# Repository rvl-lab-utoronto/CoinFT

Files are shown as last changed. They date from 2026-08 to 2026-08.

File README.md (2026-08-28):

<h1>CoinFT</h1>

#### Reproduced from [CoinFT](https://coin-ft.github.io)

Fabrication and calibration process for the CoinFTs, RVL edition. 

Please refer to their [official website](https://coin-ft.github.io) for the complete guide, this README is only intended for changes on the sensor for RVL's particular setup. 

## Catalog
- [Facility](#facility)
- [Components](#components)
- [Equipment](#equipment)
- [Fabrication](#fabrication)
- [Calibration](#calibration)
- [Sensors](#sensors)

## Facility
You'll need access to [CRAFT](https://craftmicrofluidics.ca/status-access/), it's one of the facilities at UofT that offers rental services for a degas chamber and a spin coater. You'll need to register a new account using RVL's payment method which you can get from Phebe. You'll also need to complete the general safety trainings. After that, you'll need to submit a request for an orientation at the <i>device foundry</i>. Finally, you'll need to book a training for the spin coater. In this case, the degas chamber isn't listed on their website as a separate device, so you'll be able to use it without any additional training. 

## Components
1. [PCB files](https://github.com/coin-ft/coin-ft/tree/main/hardware_files) can be found here
   - Feel free to order more stencils but we already have 2
2. [PCB ordering instruction](https://docs.google.com/document/d/e/2PACX-1vSQ-6q2MDwoBn2g9_u95RpvHrBDzH095R--uHuNxioFIZdZOnJKnvnTMS7yw188D1-z9awBrU9pWYNI/pub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)
3. There're some additional components needed to interface with the sensor:
   
| Item | Description | Qty | Unit Cost | Link |
|---|---|-----|---|---|
| 22 AWG wires | Signal wires | 1 | $20.50 | [link](https://www.amazon.ca/Fermerry-Stranded-Electric-Tinned-Copper/dp/B089CQHRDT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) |
| 1.25mm 4-pin JST connectors | Only use the female connectors | 1 | $11 | [link](https://www.amazon.ca/dp/B0F32G9B13?ref=ppx_yo2ov_dt_b_fed_asin_title&th=1) |
| 1.25mm 4-pin JST headers | Solder them onto the PCBs | 20 | $19.6 | [link](https://www.digikey.ca/en/products/detail/molex/0532610471/699096) 

We have a PSoC board and a Teensy 4.0 board in the lab, so you don't need to order additional ones.

4. 1200 Primer is intended to clean the surfaces of the PCB before applying the mold, the point of it is to improve adhesion. We were unable to find any 1200 Primer, so instead we used [99% IPA](https://www.amazon.ca/DELON-Isopropyl-Alcohol-percent-Rubbing/dp/B0DD4FSVT3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). It helps ensure that the surfaces are free of dust and can somewhat improve adhesion. In this case, you don't need to use a fume hood when cleaning the surface with IPA.
5. The original silicone rubber layer was made using two types of materials: TAP Silicone RTV Mold-Making System and Smooth-On Mold Max 40. However, we were unable to find TAP Silicone, so we only have Mold Max 40. This is fine, the instructions said that either material can be used.
6. The following picture shows some more components that we'll need, which we already have in the lab:
 Screenshot 2026-08-27 at 10 46 31 AM
7. We are replacing the acrylic parts with 3D printed parts including the holder for the PCBs, the guide rings for the weights and the calibration base. The CAD files can be found in the `CAD` folder.

## Equipment
1. A soldering iron
2. A 3D printer

## Fabrication 
The [official hardware instructions](https://docs.google.com/presentation/d/1NiOAXyq2A7fU8aHAD35k3iYaZIU_IhwRRHh8g923IFc/edit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) 
- Top:
   1. Sand and clean the PCBs (with IPA 99%) at Myhal
   2. Carry the PCBs in a Petri dish to CRAFT (at Bahen). Mix and degas the chemical mixtures (Mold Max 40 part A & B), then apply the mold.
   3. Leave the PCBs to cure at Myhal for 24 hours
- Bottom:
   1. Sand and clean the PCBs
   2. Bring the cured top PCB and the sanded bottom PCB to CRAFT.
   3. Mix and degas the chemical mixtures (1400 RPM for 2 minutes), then spin coat the bottom PCB at 3100 RPM for 1 minute and 20 seconds (you will have to experiment with the exact time)
   4. Place the top PCB on top of the bottom PCB and leave it to cure for 24 hours (or longer)
- Soldering:
  1. Solder the yellow shielding to GND (G) not SHD, do not follow their tutorial.
- Sanding: 
  <i>Do not sand too much!</i> 
The following picture shows the amount of sanding you should aim for. You can sand a little more, but try to get a more even exposure.



## Calibration
CoinFT doesn't directly return FT values, instead it measures capacitance which we need to map to the corresponding FT values. So, we'll use the Bota SensOne FT sensors as the reference/ground truth to calibrate the CoinFT.

Bota sensors show fewer oscillations at lower frequencies, and for a sensitive device like CoinFT, it is preferable to operate the Bota sensors at a frequency of around 400Hz or less.
 
When collecting data to train the model, start with slower presses to get a sense of the sensors’ sensitivities and to ensure that the CoinFTs and Bota are properly synced.

For reference, ~15 training sets (30s each) of stationary objects + slow presses should give you results like this, with mean-squared error per axis (Newtons): Fx: 0.000512, Fy: 0.000391, and Fz: 0.053102
CFT24_MLP_test_force_results

The PSoC board (the red one) should be used to flash and calibrate the CoinFT sensor. Once the board has been calibrated, remove all the soldered wires from the sensor and reconnect the signal connections to the Teensy board. [Link to the Teensy code](https://github.com/coin-ft/coin-ft/tree/main/hardware_files/Teensy)

## Sensors
As of September 2026, there are three fabricated CoinFT sensors in the lab labeled A, B and C.

I have uploaded the firmware for sensor A, B and C (they are ready to use) and trained individual models for sensors A and B, located in the `trained_model` folder.

The sensors may need to be recalibrated given that the rubber ages and becomes less elastic. If recalibration is needed, follow the instructions in README.md inside the `src` folder to collect and re-train the models.

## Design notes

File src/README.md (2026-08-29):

## Setup
Ensure the correct orientation


## Notes
1. Run sudo for every file
2. The Bota sensor is collecting data at 400Hz.
3. Both sensors stop collecting at the same time, the collected dataset is then trimmed by `trim_duration` from the end of the episode, ensuring that the timestamps are synced. <i>The sensors are NOT hardware synced</i>. 
4. The total collection time is `trim_duration` + 5s
5. You will need to intentionally twist the top PCB around the Z-axis to collect sufficient data for training the Z-axis torque (ie Mz), otherwise the trained model may not be accurate. 

## Run
`sudo python3 coinft_tune.py --data_type train --bota_rate 400 --trim_duration 30`
- data_type: train, test or val 
- bota_rate: default 400Hz
- trim_duration: length of each episode, default 30s

Run this after all data has been collected:
`sudo python3 data_processor.py`

Train the model:
`sudo python3 coinft_MLP_train.py`

Run CoinFT live:
`sudo python3 live_eval.py --model_dir sensor_A --recording_time 30`
for models located in the `/trained_model/sensor_A` folder

## Models
1. `/trained_model/sensor_A` is trained on 18 episodes, 30s per episode, with Bota's frequency set to 400Hz.

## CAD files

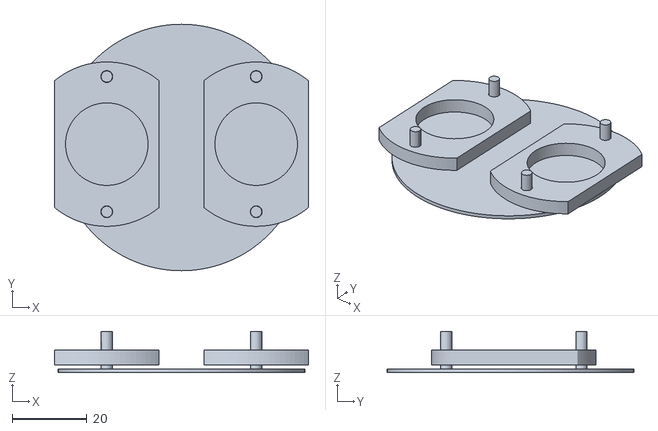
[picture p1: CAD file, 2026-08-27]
CAD/CoinFT_base.stl
68.0 x 66.0 x 11.0

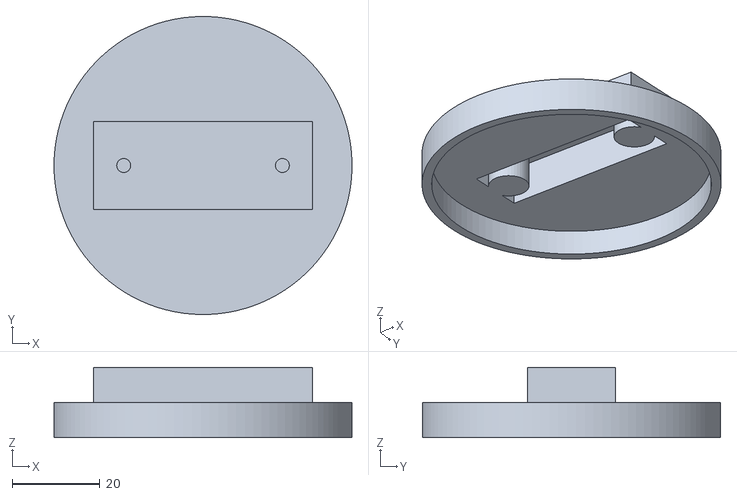
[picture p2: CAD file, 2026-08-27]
CAD/CoinFT_Testbed.stl
68.0 x 68.0 x 16.0

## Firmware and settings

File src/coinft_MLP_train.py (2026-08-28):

import torch
import torch.nn as nn
import torch.optim as optim
from torch.utils.data import Dataset, DataLoader
import numpy as np
import h5py
import json
import matplotlib.pyplot as plt
import os

# --- CONFIGURATION ---
BATCH_SIZE = 32
LEARNING_RATE = 1e-3
EPOCHS = 30
L2_REG = 1e-4  # L2 Regularization
SEED = 42
SENSOR_NAME = "CFT24"
MODEL_NAME = f"{SENSOR_NAME}_MLP"

SCRIPT_DIR = os.path.dirname(os.path.abspath(__file__))
DATA_DIR = os.path.join(SCRIPT_DIR, '..', 'data')
CONFIG_DIR = os.path.join(SCRIPT_DIR, '..', 'hardware_configs')

# Force CPU (no CUDA)
device = torch.device("cpu")
print(f"Using device: {device}")

# Set random seed for reproducibility
torch.manual_seed(SEED)
np.random.seed(SEED)

# --- 1. DATASET CLASS ---
class CoinFTDataset(Dataset):
    def __init__(self, h5_path):
        # Load data into memory
        with h5py.File(h5_path, 'r') as f:
            self.X = torch.tensor(f['data'][:], dtype=torch.float32)
            self.Y = torch.tensor(f['label'][:], dtype=torch.float32)

    def __len__(self):
        return len(self.X)

    def __getitem__(self, idx):
        return self.X[idx], self.Y[idx]

# --- 2. NETWORK ARCHITECTURE ---
class CoinFTNet(nn.Module):
    def __init__(self, input_dim, output_dim):
        super(CoinFTNet, self).__init__()
        self.net = nn.Sequential(

            # Layer 1: 128
            nn.Linear(input_dim, 128),
            nn.ReLU(),

            # Layer 2: 64
            nn.Linear(128, 64),
            nn.ReLU(),

            # Layer 3: 36
            nn.Linear(64, 36),
            nn.ReLU(),

            # Layer 4: 24
            nn.Linear(36, 24),
            nn.ReLU(),

            # Layer 5: 12
            nn.Linear(24, 12),
            nn.ReLU(),

            # Output Layer: 6 (Regression)
            nn.Linear(12, output_dim)
        )

    def forward(self, x):
        return self.net(x)

def train_pipeline():
    # --- 3. DATA LOADING ---
    print("Loading datasets...")
    train_dataset = CoinFTDataset(os.path.join(DATA_DIR, 'train.h5'))
    val_dataset   = CoinFTDataset(os.path.join(DATA_DIR, 'val.h5'))
    test_dataset  = CoinFTDataset(os.path.join(DATA_DIR, 'test.h5'))

    train_loader = DataLoader(train_dataset, batch_size=BATCH_SIZE, shuffle=True)
    val_loader   = DataLoader(val_dataset, batch_size=BATCH_SIZE, shuffle=False)
    # Test loader: batch_size = total size to predict all at once later
    test_loader  = DataLoader(test_dataset, batch_size=len(test_dataset), shuffle=False)

    # Determine dimensions dynamically
    input_dim = train_dataset.X.shape[1]  # Should be 12 based on CoinFT raw data
    output_dim = train_dataset.Y.shape[1] # Should be 6 (Fx...Mz)
    print(f"Input Dim: {input_dim}, Output Dim: {output_dim}")

    # --- 4. MODEL SETUP ---
    model = CoinFTNet(input_dim, output_dim).to(device)

    # Loss function (RegressionLayer)
    criterion = nn.MSELoss()

    # Optimizer (Adam with L2 Regularization)
    optimizer = optim.Adam(model.parameters(), lr=LEARNING_RATE, weight_decay=L2_REG)

    # --- 5. TRAINING LOOP ---
    print("\nStarting training...")
    train_losses = []
    val_losses = []

    for epoch in range(EPOCHS):
        model.train()
        running_loss = 0.0

        for X_batch, Y_batch in train_loader:
            X_batch, Y_batch = X_batch.to(device), Y_batch.to(device)

            optimizer.zero_grad()           # Clear gradients
            outputs = model(X_batch)        # Forward pass
            loss = criterion(outputs, Y_batch) # Compute loss
            loss.backward()                 # Backward pass
            optimizer.step()                # Update weights

            running_loss += loss.item() * X_batch.size(0)

        epoch_train_loss = running_loss / len(train_dataset)
        train_losses.append(epoch_train_loss)

        # Validation Step
        model.eval()
        val_loss = 0.0
        with torch.no_grad():
            for X_val, Y_val in val_loader:
                X_val, Y_val = X_val.to(device), Y_val.to(device)
                preds = model(X_val)
                loss = criterion(preds, Y_val)
                val_loss += loss.item() * X_val.size(0)

        epoch_val_loss = val_loss / len(val_dataset)
        val_losses.append(epoch_val_loss)

        print(f"Epoch {epoch+1}/{EPOCHS} | Train Loss: {epoch_train_loss:.6f} | Val Loss: {epoch_val_loss:.6f}")

    print("Training complete.")

    # --- 6. SAVE MODEL (PyTorch & ONNX) ---
    pth_path = os.path.join(CONFIG_DIR, f"{MODEL_NAME}.pth")
    onnx_path = os.path.join(CONFIG_DIR, f"{MODEL_NAME}.onnx")

    # Save standard PyTorch model
    torch.save(model.state_dict(), pth_path)

    # Export to ONNX
    dummy_input = torch.randn(1, input_dim).to(device)
    torch.onnx.export(model, dummy_input, onnx_path,
                      input_names=['input'], output_names=['output'])

    print(f"Models saved to:\n  {pth_path}\n  {onnx_path}")

    # --- 7. EVALUATION & DENORMALIZATION ---
    print("\nEvaluating on Test Set...")

    # Load Normalization Constants
    with open(os.path.join(CONFIG_DIR, f'{SENSOR_NAME}_norm.json'), 'r') as f:
        norm = json.load(f)
        mu_y = np.array(norm['mu_y'])
        sd_y = np.array(norm['sd_y'])

    model.eval()
    with torch.no_grad():
        # Get all test data
        X_test, Y_test_norm = next(iter(test_loader))
        X_test = X_test.to(device)

        # Predict (Normalized Space)
        pred_norm = model(X_test).cpu().numpy()
        Y_test_norm = Y_test_norm.numpy()

        # Denormalize: pred = pred_n * std + mean
        pred_real = (pred_norm * sd_y) + mu_y
        Y_test_real = (Y_test_norm * sd_y) + mu_y

    # Calculate MSE per axis
    mse_per_dim = np.mean((pred_real - Y_test_real)**2, axis=0)

    labels = ['Fx', 'Fy', 'Fz', 'Mx', 'My', 'Mz']
    print("\nMean-squared error per axis (Newtons / Nm):")
    for i, label in enumerate(labels):
        print(f"  {label} : {mse_per_dim[i]:.6f}")

    # --- 8. VISUAL CHECK (Matplotlib) ---
    plot_len = len(Y_test_real)

    fig, axs = plt.subplots(3, 2, figsize=(10, 10))
    axs = axs.ravel()

    for i in range(6):
        axs[i].plot(Y_test_real[:plot_len, i], 'b-', label='True')
        axs[i].plot(pred_real[:plot_len, i], 'r--', label='Pred')
        axs[i].set_title(f'Axis {labels[i]}')
        if i == 0: axs[i].legend()

    plt.tight_layout()

    fig_path = os.path.join(DATA_DIR, f"{MODEL_NAME}_results.png")
    plt.savefig(fig_path)
    plt.show()

if __name__ == "__main__":
    train_pipeline()

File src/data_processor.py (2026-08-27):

import os
import glob
import numpy as np
import h5py
import json

# --- CONFIGURATION ---
SENSOR_NAME = 'CFT24'
SCRIPT_DIR = os.path.dirname(os.path.abspath(__file__))
# Path to raw data (relative to this script)
DATA_DIR = os.path.join(SCRIPT_DIR, '..', 'data')
# Path to save processed data
SAVE_DATA_DIR = os.path.join(SCRIPT_DIR, '..', 'data')
SAVE_JSON_DIR = os.path.join(SCRIPT_DIR, '..', 'hardware_configs')
JSON_FILENAME = f'{SENSOR_NAME}_norm.json'  # Name of your JSON constants file

def process_data():
    # 1. Setup Directories
    if not os.path.exists(SAVE_DATA_DIR):
        os.makedirs(SAVE_DATA_DIR)
        print(f"Created directory: {SAVE_DATA_DIR}")
    if not os.path.exists(SAVE_JSON_DIR):
        os.makedirs(SAVE_JSON_DIR)
        print(f"Created directory: {SAVE_JSON_DIR}")

    # 2. Find all HDF5 files matching the sensor name
    search_path = os.path.join(DATA_DIR, f"*{SENSOR_NAME}_calibrationData_*.h5")
    file_list = glob.glob(search_path)

    if not file_list:
        print(f"No files found in {search_path}")
        return

    print(f"Found {len(file_list)} files. Sorting by filename suffix...")

    # 3. Bucket files based on suffix (_train, _val, _test)
    data_buckets = {
        'train': {'sensor': [], 'ft': []},
        'val':   {'sensor': [], 'ft': []},
        'test':  {'sensor': [], 'ft': []}
    }

    for file_path in file_list:
        filename = os.path.basename(file_path)

        # Determine split type from filename
        if '_train.h5' in filename:
            split_type = 'train'
        elif '_val.h5' in filename:
            split_type = 'val'
        elif '_test.h5' in filename:
            split_type = 'test'
        else:
            print(f"Skipping file (unknown suffix): {filename}")
            continue

        # Load Data
        with h5py.File(file_path, 'r') as f:
            sensor_val = f['sensor_cal_data'][:]
            ft_val = f['bota_cal_FT'][:]  # was 'ati_cal_FT' -- now using Bota driver's key

            data_buckets[split_type]['sensor'].append(sensor_val)
            data_buckets[split_type]['ft'].append(ft_val)
            print(f"Loaded {split_type}: {filename}")

    # 4. Stack Arrays for each split
    # Helper to stack or return empty if no data found
    def stack_data(key):
        if not data_buckets[key]['sensor']:
            print(f"Warning: No data found for split '{key}'")
            return None, None
        return (np.vstack(data_buckets[key]['sensor']),
                np.vstack(data_buckets[key]['ft']))

    X_train, Y_train = stack_data('train')
    X_val, Y_val     = stack_data('val')
    X_test, Y_test   = stack_data('test')

    if X_train is None:
        print("Error: No training data found. Cannot compute normalization.")
        return

    print(f"\nData Split Dimensions:")

    if X_train is not None:
        print(f"Train | X: {X_train.shape}  Y: {Y_train.shape}")
    else:
        print("Train | Not found")

    if X_val is not None:
        print(f"Val   | X: {X_val.shape}  Y: {Y_val.shape}")
    else:
        print("Val   | Not found")

    if X_test is not None:
        print(f"Test  | X: {X_test.shape}  Y: {Y_test.shape}")
    else:
        print("Test  | Not found")

    # 5. Normalization (Z-Score) for INPUTS (X) AND TARGETS (Y)
    print("\nComputing normalization stats from Training set...")

    # --- INPUTS (Sensor Data) ---
    mean_X = np.mean(X_train, axis=0)
    std_X  = np.std(X_train, axis=0)
    std_X[std_X == 0] = 1.0  # Avoid division by zero

    # --- LABELS (Force/Torque Data) ---
    mean_Y = np.mean(Y_train, axis=0)
    std_Y  = np.std(Y_train, axis=0)
    std_Y[std_Y == 0] = 1.0  # Avoid division by zero

    # --- SAVE JSON CONSTANTS ---
    # We convert numpy arrays to python lists using .tolist() for JSON compatibility
    norm_constants = {
        "mu_x": mean_X.tolist(),
        "sd_x": std_X.tolist(),
        "mu_y": mean_Y.tolist(),
        "sd_y": std_Y.tolist()
    }

    json_path = os.path.join(SAVE_JSON_DIR, JSON_FILENAME)

    with open(json_path, 'w') as json_file:
        json.dump(norm_constants, json_file, indent=2)

    print(f"Saved normalization constants to: {json_path}")

    print("Normalizing X and Y data...")

    # Apply to Train
    X_train = (X_train - mean_X) / std_X
    Y_train = (Y_train - mean_Y) / std_Y

    # Apply to Val
    X_val = (X_val - mean_X) / std_X
    Y_val = (Y_val - mean_Y) / std_Y

    # Apply to Test
    X_test = (X_test - mean_X) / std_X
    Y_test = (Y_test - mean_Y) / std_Y

    # 6. Save Processed Datasets (HDF5)
    def save_h5(filename, x_data, y_data):
        if x_data is None: return

        full_path = os.path.join(SAVE_DATA_DIR, filename)
        with h5py.File(full_path, 'w') as f:
            f.create_dataset('data', data=x_data, compression='gzip')
            f.create_dataset('label', data=y_data, compression='gzip')
            # (Optional) We still save attrs in H5 for convenience,
            # even though we have the JSON now.
            f.create_dataset('mean_X', data=mean_X)
            f.create_dataset('std_X', data=std_X)
            f.create_dataset('mean_Y', data=mean_Y)
            f.create_dataset('std_Y', data=std_Y)

        print(f"Saved: {full_path}")

    save_h5('train.h5', X_train, Y_train)
    save_h5('val.h5', X_val, Y_val)
    save_h5('test.h5', X_test, Y_test)

    print("\nProcessing complete.")

if __name__ == "__main__":
    process_data()

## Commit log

2026-08-27 CAD files added
    [CoinFT_Testbed.3mf, CoinFT_base.3mf]
2026-08-27 CAD added
    [CoinFT_Testbed.3mf, CoinFT_Testbed.stl, CoinFT_base.3mf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]
2026-08-27 Add link to Teensy code in README
2026-08-28 Sensor B
2026-08-29 Update training details for sensor_A in README
    Corrected the description of the training parameters for sensor_A.
